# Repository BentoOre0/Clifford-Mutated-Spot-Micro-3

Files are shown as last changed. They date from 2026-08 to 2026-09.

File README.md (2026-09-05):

# Clifford: Mutated Spot Micro 3

<p align="center">
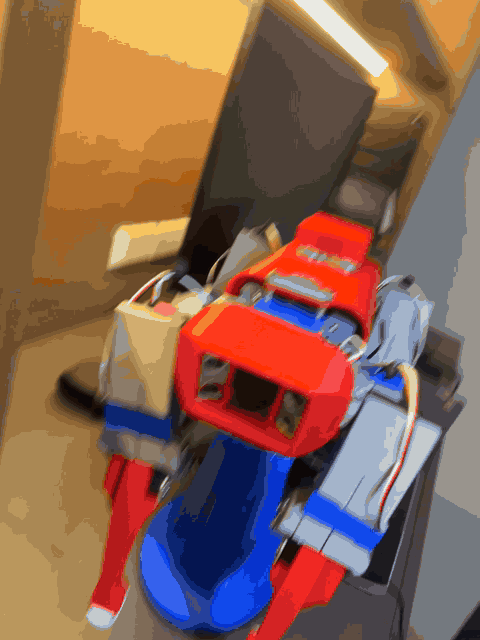
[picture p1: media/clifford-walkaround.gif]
Clifford, assembled, on the bench stand
  
</p>

**Clifford is a twelve-servo quadruped robot.** He started as
[Chris Locke's Nova SM3](https://novaspotmicro.com), an open-source Spot-Micro-class
design, and he exists in this form because the servos that design is drawn around were
not available to me. Substituting them broke every leg part at once, so the legs were
redesigned from scratch around a different servo.

That is the project: **not a build of someone else's kit, and not a design of my own from
nothing, but the engineering in between.** Adapting a working system to parts it was never
meant to use, and getting it running again.

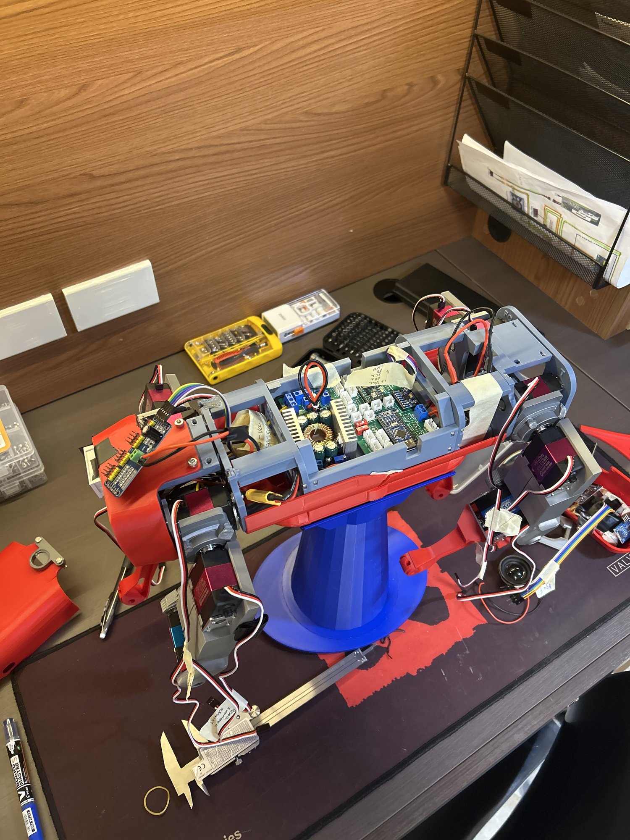
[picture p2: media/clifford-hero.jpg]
Clifford during electronics integration


*Mid-integration on the bench. The grey coax and femur and the red tibia are my geometry.
The calipers in the corner are not set dressing: every part here was redrawn against
measurements.*

---

## The problem that started everything

I built this in the Philippines, where a significant share of the original bill of
materials was not practically sourceable. The servos were the ones that mattered.

The Nova SM3 is drawn around the **DS3218** servo, which bolts down through **four sets of
mounting holes.**

The only servos I could actually buy were the **RDS3218**, which does not have those holes.
It hangs in a **U-shaped metal bracket** instead.

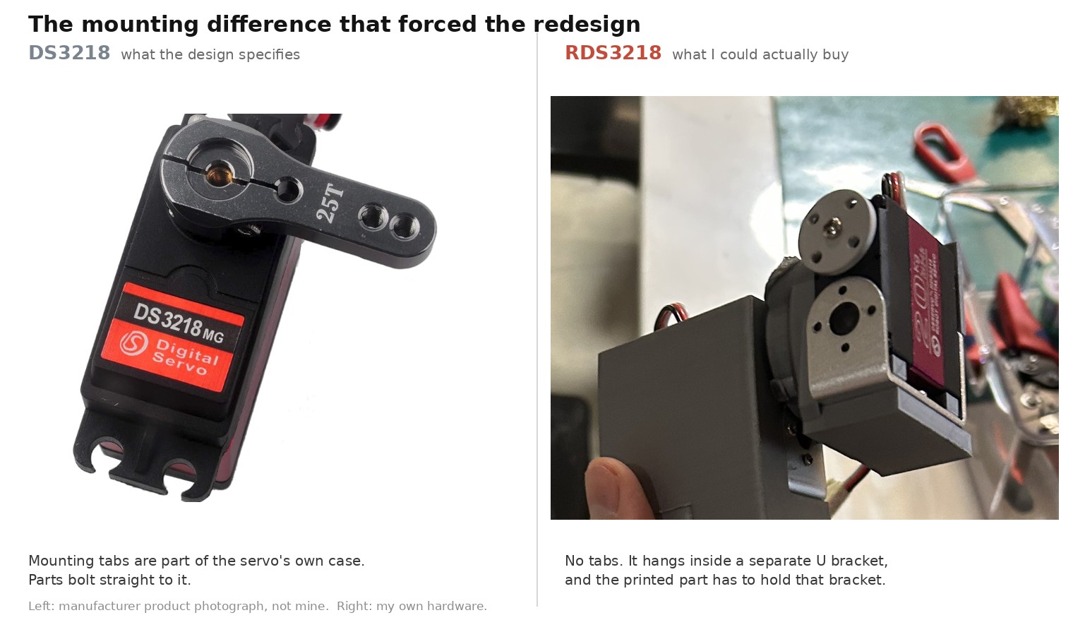
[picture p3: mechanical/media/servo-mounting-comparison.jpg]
DS3218 against RDS3218


PROBLEM: The mounting scheme every leg part was built around simply does not exist on the replacement
part. The pockets, the bosses and the screw features were all designed to grip something
that no longer had anything to grip.

SOLUTION: Each leg part had to be redesigned from scratch around a completely different way of
holding a servo, while keeping the servo horn geometry and axis position (To the best of my ability).

**Twelve servos, all 270 degrees:** 8x RDS3218 at 20 kg.cm for the coax and femur joints,
4x RDS3235 at 35 kg.cm for the knees.

---

## What I changed

| | Chris Locke's | Mine |
|---|---|---|
| Robot concept, gaits, servo motion engine, master/slave architecture | all of it | |
| Original leg geometry | the starting point | **redesigned from scratch around the RDS3218 bracket** |
| Coax, femur and tibia parts | original | **mine**, horn interface preserved |
| Printing and assembly | | **mine** |
| Wiring diagram | v5.2b pictogram | **revised for parts I could source, plus one fault corrected** |
| Power distribution | cascaded converters | **reworked to parallel** |
| PCB assembly, wiring and bring-up | | **mine** |
| Per-subsystem bench test sketches | | **mine** |
| Firmware v4.2 to v5.1 | his | |
| Firmware v6.0 restructure | behaviour is his | **reorganisation is mine** |
| Servo calibration values | **still his**, and that is the open problem | see [Status](#status) |

---

## The engineering journey

<table>
<tr>
<td width="33%" valign="top">
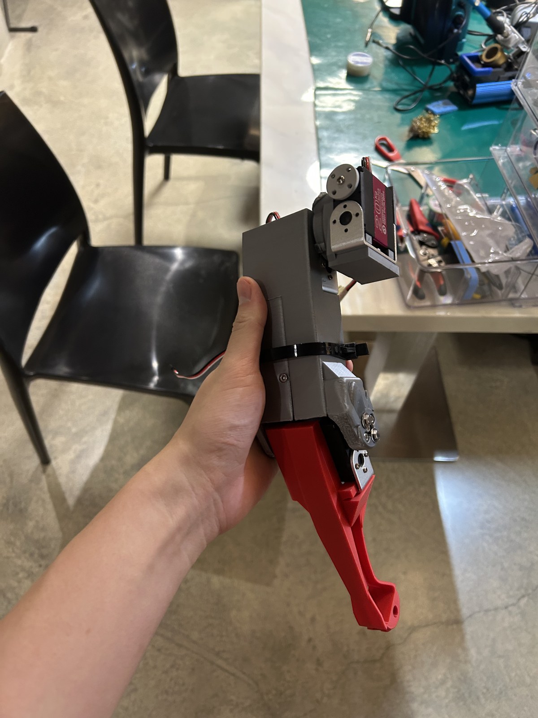
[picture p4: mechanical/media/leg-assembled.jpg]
Assembled leg

<br><b><a href="mechanical/README.md">Mechanical</a></b><br>
A servo that mounts in a bracket instead of through holes, and the three parts that had
to be redrawn because of it. Original against modified, measured from the meshes.
</td>
<td width="33%" valign="top">
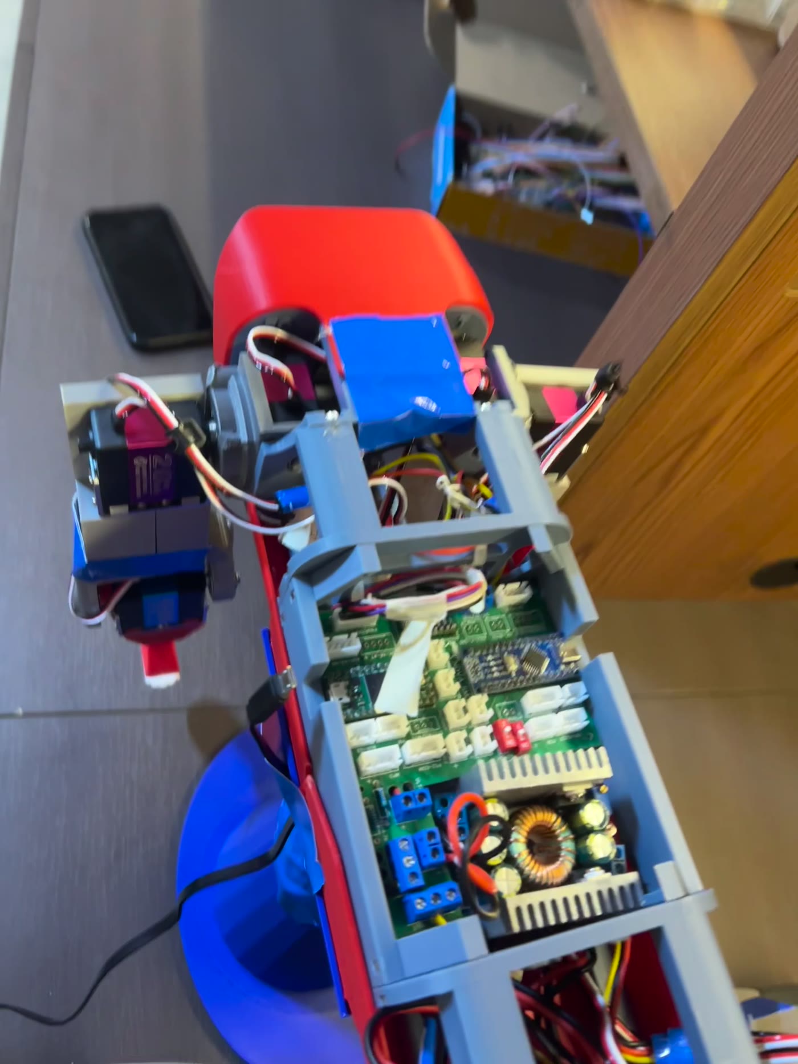
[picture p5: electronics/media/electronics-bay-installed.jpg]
Electronics bay

<br><b><a href="electronics/README.md">Electronics</a></b><br>
A reference design that had gone stale, traced by hand against real hardware. Power
rework, a wiring fault, and one subsystem brought up at a time.
</td>
<td width="33%" valign="top">
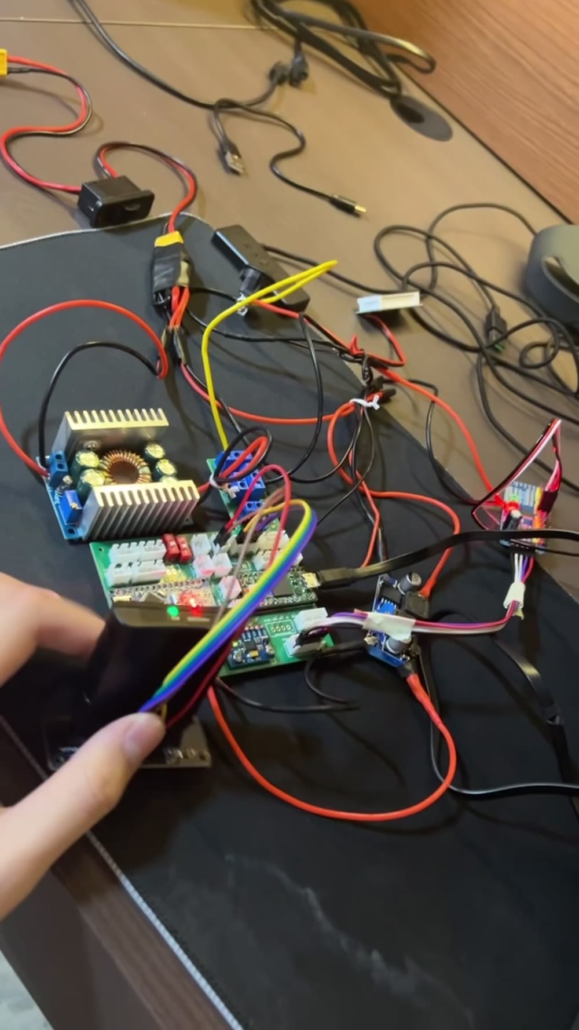
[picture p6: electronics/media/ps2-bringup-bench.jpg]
PS2 bring-up

<br><b><a href="firmware/README.md">Firmware</a></b><br>
6,390 lines in one file, 85 undocumented protocol strings, and an 812-line function.
Restructured into something maintainable, with two real bugs found on the way.
</td>
</tr>
</table>

> ### [Open the full corrected wiring diagram](electronics/wiring/wiring-diagram-modified.png)
>
> 6000 x 4712, every pin labelled, every revision marked on the sheet. The upstream
> pictogram had a short in it; this is the corrected drawing.

---

## Status

Being straight about where this actually is:

| | |
|---|---|
| Leg redesign, printing, assembly | Complete |
| Electronics integration | Complete |
| Wiring diagram corrected and revised | Complete |
| Per-subsystem bench tests | Passing |
| PS2 receiver verified against live serial output | Yes |
| Firmware v6.0 restructure | Complete, compiles clean for both boards |
| **Servo recalibration for my servos** | **Not done had to fly out to UBC** |
| **Walking** | **Not working yet** |

---

## Repository layout

```text
media/           hero photography and the walkaround clip
mechanical/      the leg redesign: CAD, comparisons, build photos
electronics/     wiring, power, PCB, bring-up
firmware/        the Arduino sketches and the v6.0 write-up
```

Chris Locke's original geometry lives in
[`mechanical/cad/original/`](mechanical/cad/original/) under his filenames and is never
edited in place. 

---

## Credit and licence

**Original project: Chris Locke** (`cguweb@gmail.com`).
[novaspotmicro.com](https://novaspotmicro.com) ·
[GitHub](https://github.com/cguweb-com/Arduino-Projects/tree/main/Nova-SM3) ·
[Thingiverse](https://www.thingiverse.com/thing:4767006) ·
[Instructables](https://www.instructables.com/Nova-Spot-Micro-a-Spot-Mini-Clone/).
MIT licensed, see [LICENSE](LICENSE), Copyright (c) 2021 Christopher M. Locke.

The robot, the pcB, its gaits, its servo motion engine and its master/slave architecture are his.
The wiring diagram here is a revision of his v5.2b pictogram: the base artwork is his and
the revisions are mine.

**Third-party images.** The DS3218 photograph in the
[mechanical write-up](mechanical/README.md) is a manufacturer product image from a retail
listing, reproduced for comparison only. It is not my photograph.

**Third-party parts.** **Ozzymat**'s [Youtube](https://www.youtube.com/@ozzymat61) was a reference for looking at physical assemblies of the original NOVA which is different. I used this as insiration for ideas on how I can make a physically new part.

**Leg redesign, electronics and v6.0 firmware restructure: Jeremy Aidan Yu.** The v6.0
restructure was done with Claude Code, which is stated here, in the firmware write-up and
in the source headers.

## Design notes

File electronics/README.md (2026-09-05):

# Electronics: wiring a reference design that had gone stale

← [back to the main README](../README.md)

---

## What is actually inside

Before any diagrams, this is the real thing:

Electronics installed

*Looking down into the open electronics bay of the assembled robot. The controller PCB is
at the bottom of the frame with the servo harnesses running out to the legs, and the
step-down converter sits above it. I hadn't soldered initensively before, I soldered everything here (PCB, MCUs, XT60 connectors) and tested connections.*

<table>
<tr>
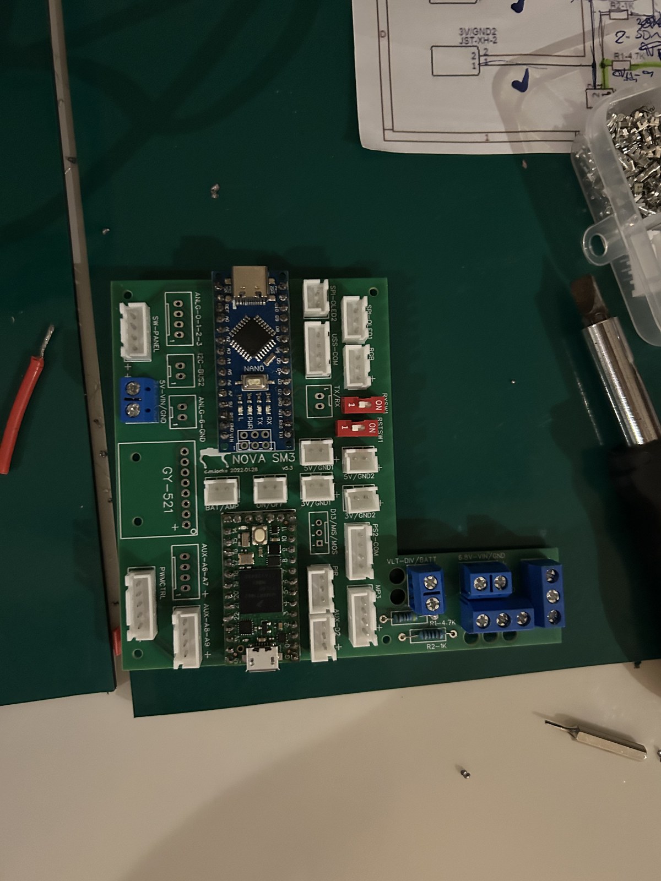
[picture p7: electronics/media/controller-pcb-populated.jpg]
Controller PCB populated
<td width="50%"></td>
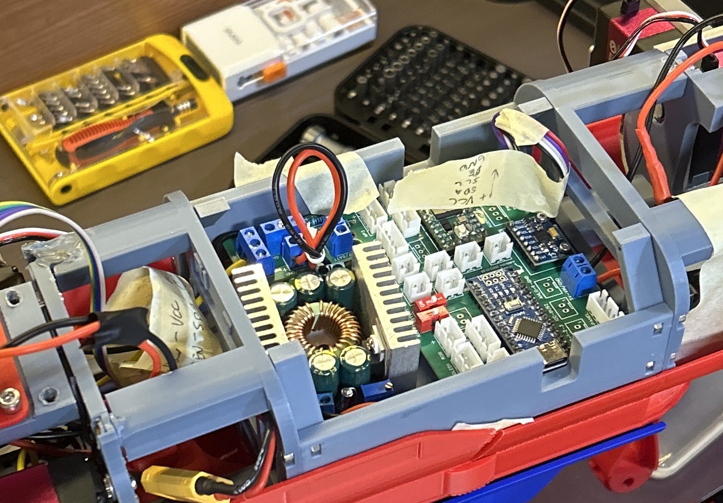
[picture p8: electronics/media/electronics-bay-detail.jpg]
Electronics bay detail
<td width="50%"></td>
</tr>
<tr>
<td colspan="2"><em>Left: the Nova SM3 controller board after I populated and soldered it,
before installation. It is the Chris' project's own PCB (which I had to adopt by rerouting components), not an off-the-shelf module: JST servo
headers, an Arduino Nano, an MPU6050 breakout, a DIP switch and screw terminals. Right: the
same board fitted in the chassis beside the converter. The masking-tape labels reading
<code>+VCC / SDA / SCL / OE / GND</code> are mine, written during bring-up so the I2C and
output-enable lines could be traced against the drawing without counting pins every
time.</em></td>
</tr>
</table>

**What has to be powered:** twelve servos, two microcontrollers, an IMU, three PIR sensors,
two ultrasonic sensors, an OLED, four addressable RGB LEDs, an MP3 player and a speaker,
all from one LiPo pack. 

---

## The pictogram was wrong. The schematic is what proved it

The upstream project ships two wiring documents, a **schematic** and a **pictogram**, and
they do not agree with each other. The schematic is accurate. The pictogram belongs to an
older, deprecated revision, and following it as drawn does not give you a working robot.

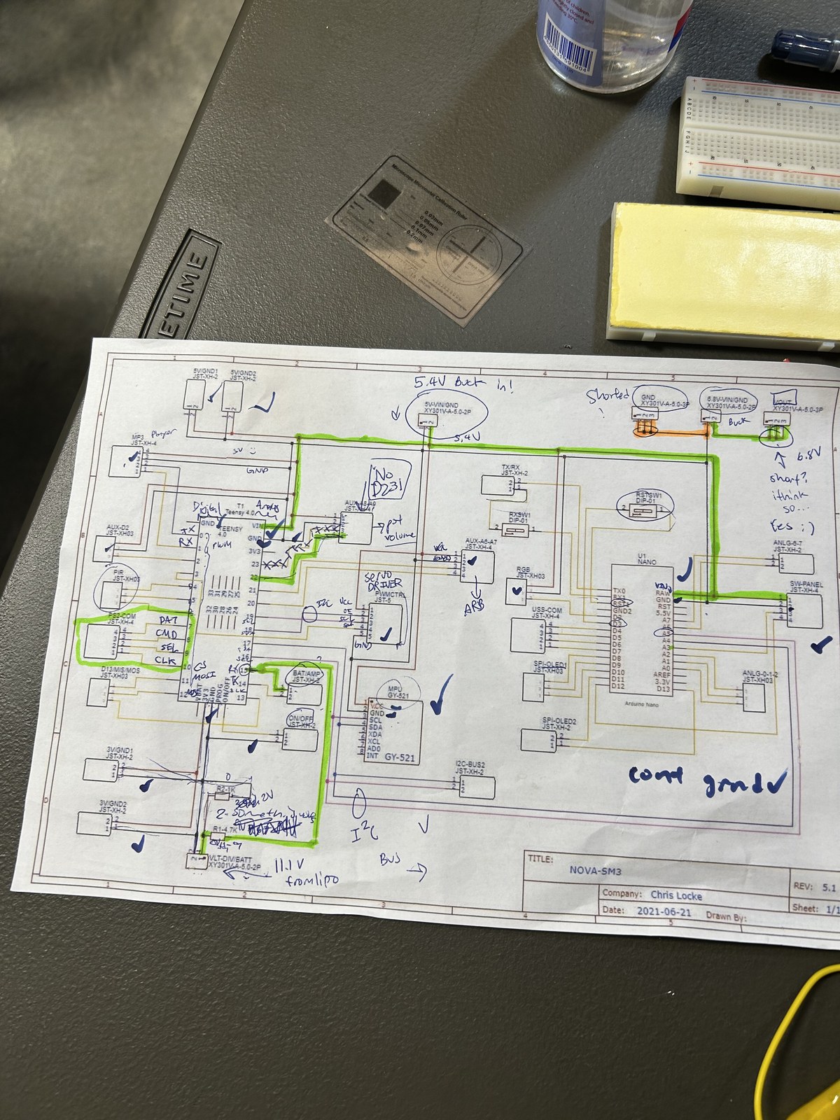
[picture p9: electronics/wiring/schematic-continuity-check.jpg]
Schematic used as a test sheet


*Chris Locke's REV 5.1 schematic, printed and used as a live test sheet. This is the
drawing that held up under testing, which is why it became my reference. Blue ticks are
nets I confirmed with a multimeter, green highlighter follows the ones I was chasing to get an understanding of the structure, the
PS2-COM header is hand-labelled DAT / CMD / SEL / CLK because that mapping had to be worked
out, and `cont gnd` with a tick at the bottom records ground continuity confirmed. I did this by doing a disjoint set union approach for continuity.
The ports for grounds werenodes, the traces between them are edges, just run DSU and make sure everything is continuous!*

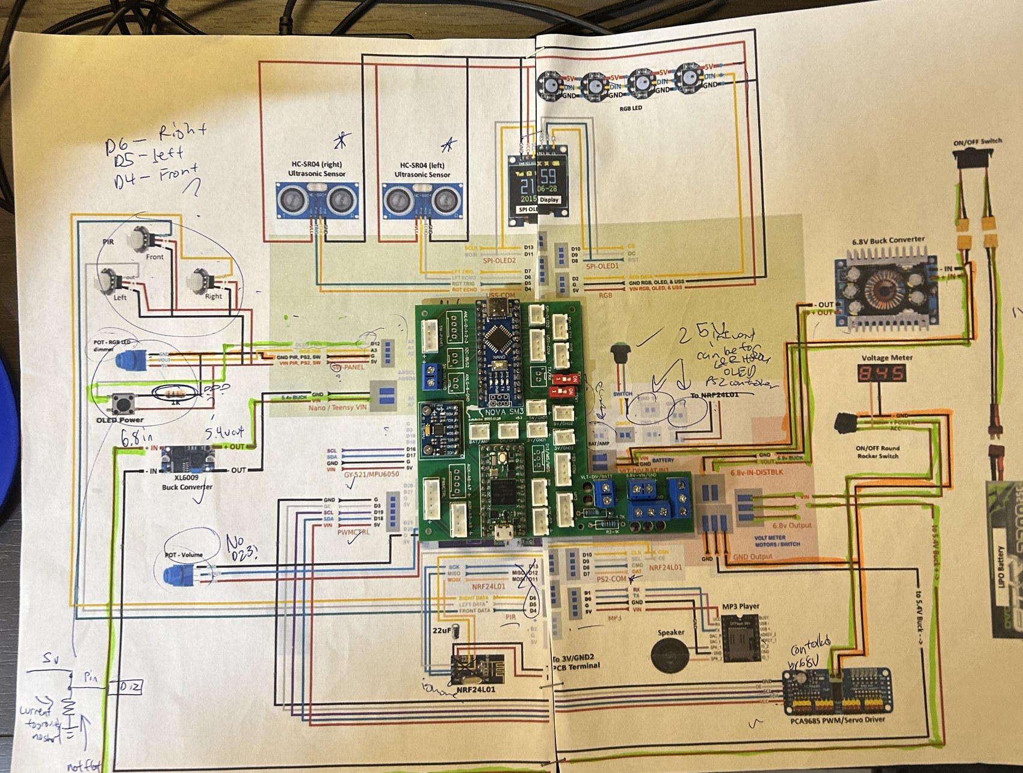
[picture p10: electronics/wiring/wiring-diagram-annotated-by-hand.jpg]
Pictogram traced by hand


*The v5.2b pictogram, traced in highlighter along the power path with pen notes throughout*

I found quite a few errors, some by tracing and some by physical building and realising things didnt turn on consistently.
The output of all of this is a **corrected pictogram**, which carries its own
revision block that also shows my modifications:

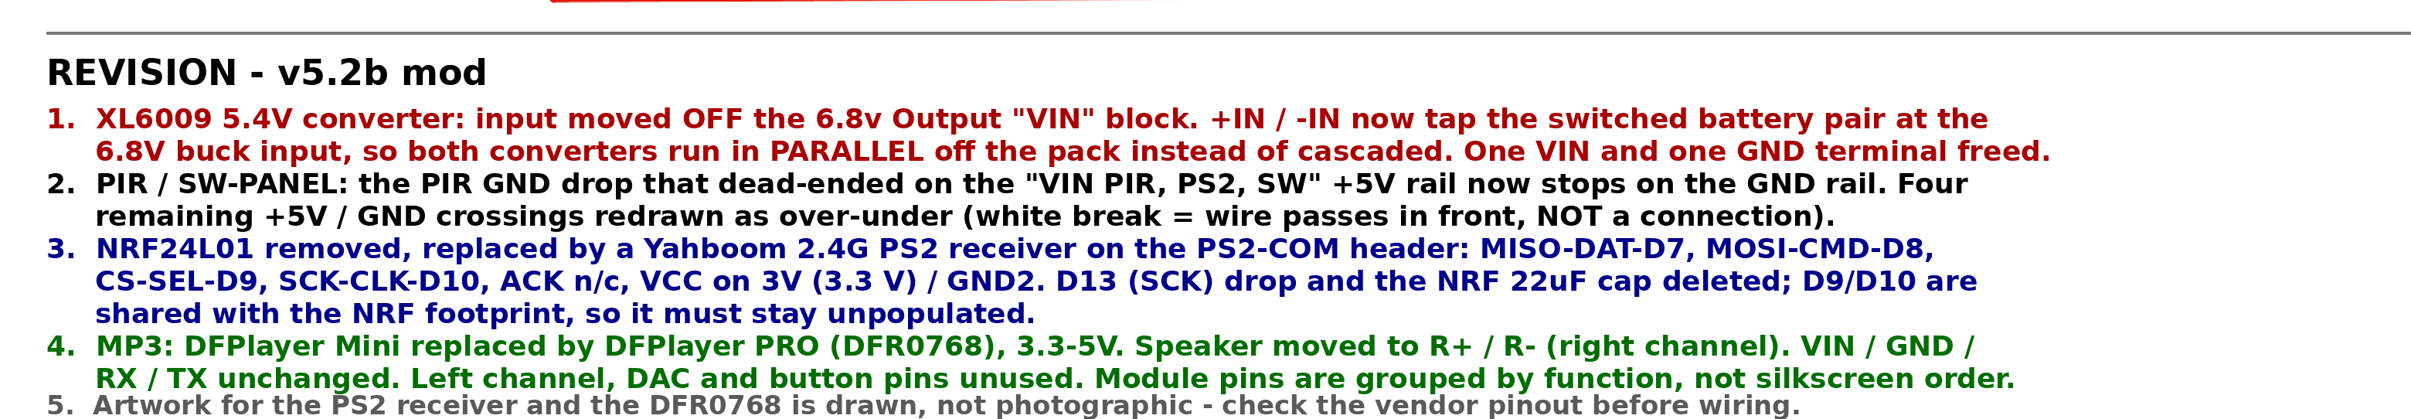
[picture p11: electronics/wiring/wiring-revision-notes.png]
Revision block


> ## [Open the full corrected wiring diagram](wiring/wiring-diagram-modified.png)
>
> `electronics/wiring/wiring-diagram-modified.png`, 6000 x 4712. Every pin is labelled and
> every revision is marked on the sheet. This is the drawing to build from.

The base artwork is Chris Locke's. The revisions and the revision block are mine. It is
committed as the drawing itself rather than redrawn or summarised, so the documentation and
the artifact cannot drift apart the way the upstream pair did.

---

## Revision 1: cascaded converters reworked to parallel

**The symptom.** Startup was inconsistent. When I connected the ps2 controller and the servo driver to the pcb
while powering it, it would inconsistently start up. MCUs would not even power sometimes.
However if I didn't plug them in or plugged them in hot, these components would turn on.

**The hypothesis.** - one thing that I could see for sure is that there was a consistent **inconsistent** start up problem. When I put the 
ps2 controller and servo driver it would have a hard time starting up despite drawing only very little amps (don't remember the number).
I thought there could be some **impedance** problem between the bucks and all components: testing with multi meter I saw the 6.8V buck converter sagged 
causing the voltage down stream to sag as well. 

**What the reference design did.** The XL6009 5.4 V converter took its input from the
**6.8 V converter's output block**. The two converters therefore ran **in series**.

**The fix.** I moved the XL6009 input **off** the 6.8 V output block and onto the switched
battery pair at the 6.8 V buck input. **Both converters now run in parallel off the pack**,
so neither sees the other's output impedance.

> Revision 1, in the drawing's own words: *"XL6009 5.4V converter: input moved OFF the 6.8v
> Output 'VIN' block. +IN / -IN now tap the switched battery pair at the 6.8V buck input, so
> both converters run in PARALLEL off the pack instead of cascaded. One VIN and one GND
> terminal freed."*

## Revision 2: the PIR short

This is the fault that made the exercise worth doing. On the pictogram, **the PIR ground
drop terminated on the `VIN PIR, PS2, SW` +5 V rail** instead of the ground rail.

Wired as drawn, that ties a ground return straight to a +5 V rail, which is a short across
the sensor supply.

So I fixed it. I mentioned the changes I wanted to claude and it ran the photoshop for me.

## Revisions 3 to 5: component substitutions

| Original | What I fitted | Consequence |
|---|---|---|
| NRF24L01 plus a custom-built remote | **Yahboom 2.4 G PS2 receiver** | On the PS2-COM header: MISO-DAT-D7, MOSI-CMD-D8, CS-SEL-D9, SCK-CLK-D10, ACK n/c, **VCC on 3.3 V**, GND2. The D13 (SCK) drop and the NRF 22 uF cap are deleted. D9/D10 are shared with the NRF footprint, **so that footprint must stay unpopulated.** |
| DFPlayer Mini | **DFPlayer PRO (DFR0768)**, 3.3 to 5 V | Speaker moved to R+ / R- (right channel). VIN / GND / RX / TX unchanged; left channel, DAC and button pins unused. |

The receiver itself had nowhere to live, since the body was designed around a radio
soldered to the board. It ended up in a backpack borrowed from the Nova SM2, mounted on a
new back panel so it protrudes from the body like a tail and keeps its antenna outside the
electronics bay. That is documented on the
[mechanical page](../mechanical/README.md#the-tail-borrowing-a-backpack-from-the-nova-sm2).

Revision 5 is a caveat I put on the drawing rather than a change: the artwork for the PS2
receiver and the DFR0768 is **drawn, not photographic**, so check the vendor pinout before
wiring.

The PS2 substitution is also why the firmware runs on the older PS2 code path rather than
upstream's newer nRF path. See the [firmware write-up](../firmware/README.md).

---

## Bring-up: one subsystem at a time

The decision that mattered most was **not** to assemble everything, flash the full
firmware, and start guessing.

The inherited firmware is large, it drives a lot of peripherals, and a fault could be in my
soldering, my wiring, my power rail, or somebody else's code. Debugging all of those at once
is how you lose a week. Given that the reference documentation had already proven unreliable,
assuming any of it was correct would have been a mistake.

So I wrote [`firmware/Tests/`](../firmware/Tests/): eight standalone sketches, one per
peripheral, each of which deliberately includes **none** of the main firmware. A pass proves
wiring and hardware, not the main sketch.

| Sketch | Board | Under test | Pins, as defined in the sketch |
|---|---|---|---|
| `Test_PWM_Servos` | Teensy 4.0 | PCA9685 and 12 servos | `OE_PIN 3`, jogged over PS2 |
| `Test_PS2` | Teensy 4.0 | PS2 receiver | DAT 7, CMD 8, SEL 9, CLK 10 |
| `Test_MPU6050` | Teensy 4.0 | IMU | SDA2 17, SCL2 16 |
| `Test_PIR` | Teensy 4.0 | 3x PIR | front 4, left 5, right 6 |
| `Test_MP3` | Teensy 4.0 | DFPlayer | volume pot 20 |
| `Test_Ultrasonic` | Arduino Nano | 2x HC-SR04 | L trig 7 / echo 6, R trig 5 / echo 4 |
| `Test_OLED` | Arduino Nano | SSD1331 96x64 | active pin 12 |
| `Test_NeoPixel` | Arduino Nano | 4x WS2812 | data 2, brightness pot A3 |

Each carries an explicit pass criterion, so "it did something" does not get mistaken for
"it works".

<table>
<tr>
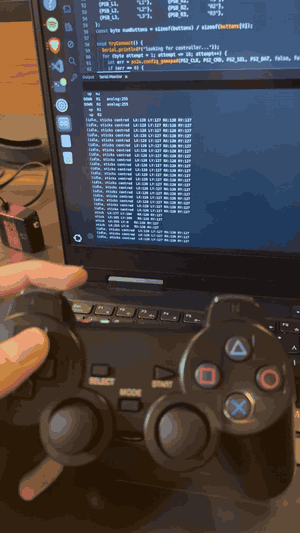
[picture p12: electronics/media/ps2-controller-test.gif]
PS2 controller tested against live serial output
<td width="42%"></td>
<td width="58%">PS2 bring-up bench rig</td>
</tr>
<tr>
<td colspan="2"><em>Left: the PS2 receiver being verified. Every button press and stick
movement is echoed by the serial monitor on the laptop, which is the firmware's
<code>ps2_debug_report()</code> running. That is what "the receiver works" actually looks
like: not a robot twitching, but a named input arriving as a value you can read. Right: the
rig it was done on, converter and controller board and jumper harness on the bench, well
away from twelve servos.</em></td>
</tr>
</table>

---

## Hazards worth knowing

These are in the source as warnings because they were live problems, not hypotheticals.

**The Teensy 4.0 is not 5 V tolerant.** From
[`Test_PS2.ino`](../firmware/Tests/Test_PS2/Test_PS2.ino): *"The PS2 receiver is a 3.3V
part. The Teensy 4.0 is ALSO 3.3V and is NOT 5V tolerant, do not feed the receiver 5V and
then wire DAT back to the Teensy."* The failure mode is nasty because the receiver **works**
on 5 V. It just quietly destroys the microcontroller through the data line. The corrected
drawing accordingly puts the receiver's VCC on 3.3 V.

**`OE_PIN` is active LOW, and boot order matters.** Driving OE low *enables* the servos. It
is held high through boot until the PS2 link is up, because the PWM driver interferes with
the receiver; without that sequencing the robot lurches on power-up. Servo output arms about
a second after boot.

**Current sense and battery sense share one pin.** `AMP_PIN` and `BATT_MONITOR` are both
**A1**. The robot physically cannot measure servo current and battery voltage at the same
time. This is inherited from the original design and is an architectural limitation, not a
bug.

**Debug flags block an untethered boot.** On a Teensy, printing to a serial port with
nothing attached stalls the board, so any debug flag left set in `NovaConfig.h` makes the
robot appear completely dead the moment you unplug the laptop.

---

## What is not documented here

- **No measurements recorded.** No current draw figures, no rail voltages under load, no
  scope captures. The reasoning above and the corrected drawing are the evidence; I did not
  log the readings that led me there and I am not going to invent them after the fact.
- **No continuity log.** The tracing happened, and the annotated printouts above are what
  survives of it. The individual readings were not written down.
- **No bill of materials** for the substituted parts beyond what the drawing names.

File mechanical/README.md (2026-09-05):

# Mechanical: redesigning the legs around a servo that mounts differently

← [back to the main README](../README.md)

---

## The constraint

The Nova SM3 is drawn around the **DS3218** servo. That servo bolts down through **four
sets of mounting holes**, and every leg part in the original design is built to take it:
pockets sized to the case, bosses positioned under those four hole sets, walls that clamp
around the body.

The only servo I could buy was the **RDS3218**. Electrically and dimensionally it is a
close relative. Mechanically it is not: it has no four-hole pattern. It **hangs in a
U-shaped metal bracket**, and the bracket is how it attaches to anything.

DS3218 against RDS3218

*The whole mechanical project in one image. On the DS3218 the mounting tabs are moulded into the case,
so a printed part bolts directly to the servo. The RDS3218 has none, and is instead
suspended in a separate metal bracket, which means the printed part has to capture the
bracket rather than the servo. The DS3218 photograph is a manufacturer product image
reproduced for comparison and is not my own.*

**The servos, all 270 degrees:**

| Joint | Servo | Torque | Count |
|---|---|---|---|
| Coax (hip) | RDS3218 | 20 kg.cm | 4 |
| Femur (thigh) | RDS3218 | 20 kg.cm | 4 |
| Tibia (knee) | RDS3235 | 35 kg.cm | 4 |

---

## The one thing that could not move

> **Preserve the servo horn interface exactly. Rebuild everything around it.**

The horn is where the joint axis lives. Shift it a few millimetres and every link length
in the leg changes, and the hand-tuned gait multipliers in
[`Gaits.ino`](../firmware/Nova-SM3_teensy-v6.0/Gaits.ino) stop describing the robot. (Goal is to minimise this)

---

## How the bracket problem was actually solved

The RDS3218 sits inside its U bracket, which leaves two things to design against:

**1. Two protrusions that slot between the bracket arms.** Rather than trying to clamp the
servo body, the printed part carries two protrusions that locate into the gap between the
U bracket and the servo, so the bracket itself does the holding and the print just captures
it.

**2. Four holes underneath.** The bracket is then fixed down through four holes in the
bottom face of the part.

**3. A clearance cut for the far end.** The RDS3218 has a protrusion on the end opposite
the horn, the mating feature for the other side of the U bracket. That protrusion turned
out to be **axially aligned with the servo horn and with the bearing boss**, which meant a
single extrude cut along that axis cleared it. 

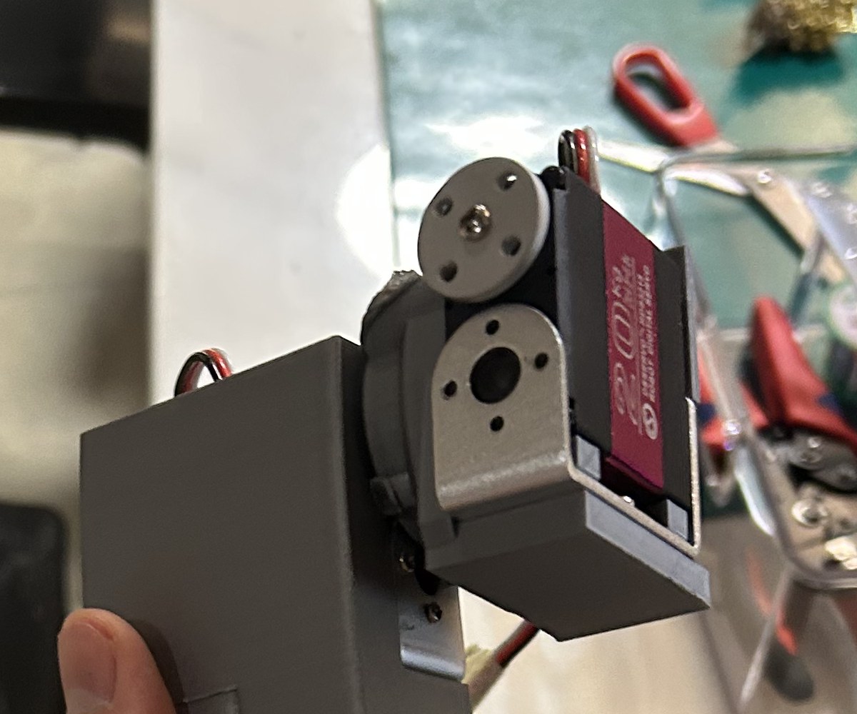
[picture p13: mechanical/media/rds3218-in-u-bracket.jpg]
RDS3218 sitting in its U bracket


*The arrangement the parts had to be redesigned for. The servo is held by the aluminium U
bracket wrapped around it, not by screws through its own case, and the printed part is
built to capture that bracket. The horn, with its five-hole pattern, is the one feature
carried over unchanged from the original design. The magenta label reads 20 kg.*

<table>
<tr>
<td width="50%">Assembled leg, front</td>
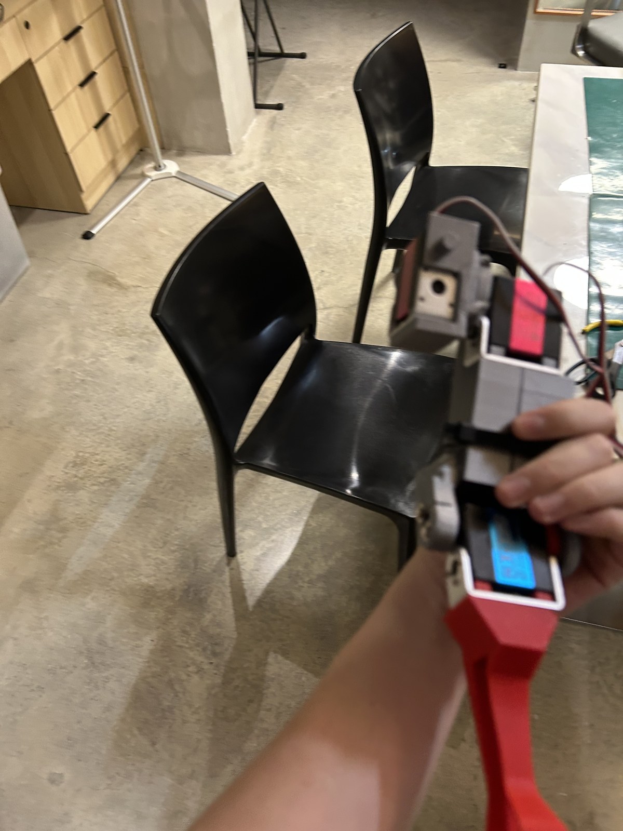
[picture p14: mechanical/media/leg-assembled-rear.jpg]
Assembled leg, rear
<td width="50%"></td>
</tr>
<tr>
<td colspan="2"><em>A complete leg. Grey parts are the coax and the two femur pieces, the
red part is the tibia. The parting line across the grey femur with the tie around it is
the joint between femur body 1 and body 2: like the original, the femur prints as two
pieces. The servos are visible sitting in their brackets.</em></td>
</tr>
</table>

---

## How the parts were modified

The parts are not redrawn from scratch in CAD, and not mesh-edited either. The workflow
was chosen to **preserve geometry that still worked**, in particular the TPU foot mounting and the servo horn mounting
holes and shape of legs, which were among the few original components I could still use:

1. **Tinkercad** for the rough cutting and the crude changes, working directly on the
   original STL. Fast, and good enough to hack away what the new servo made irrelevant
   while leaving the features worth keeping alone.
2. **Formware** to patch the mesh afterwards. Boolean cuts on an STL leave a damaged,
   non-manifold shell, and that has to be repaired before anything downstream will accept
   it. The intermediate file in my working set is still named after this step.
3. **SolidWorks** for the formal parametric work: import the repaired mesh as a base solid
   body, then add real sketches, boss-extrudes and cut-extrudes on top.

That sequence is visible in the feature trees. The coax part opens with `Imported1`,
Chris Locke's geometry, and then carries my own sketches and features on top of it:

<table>
<tr>
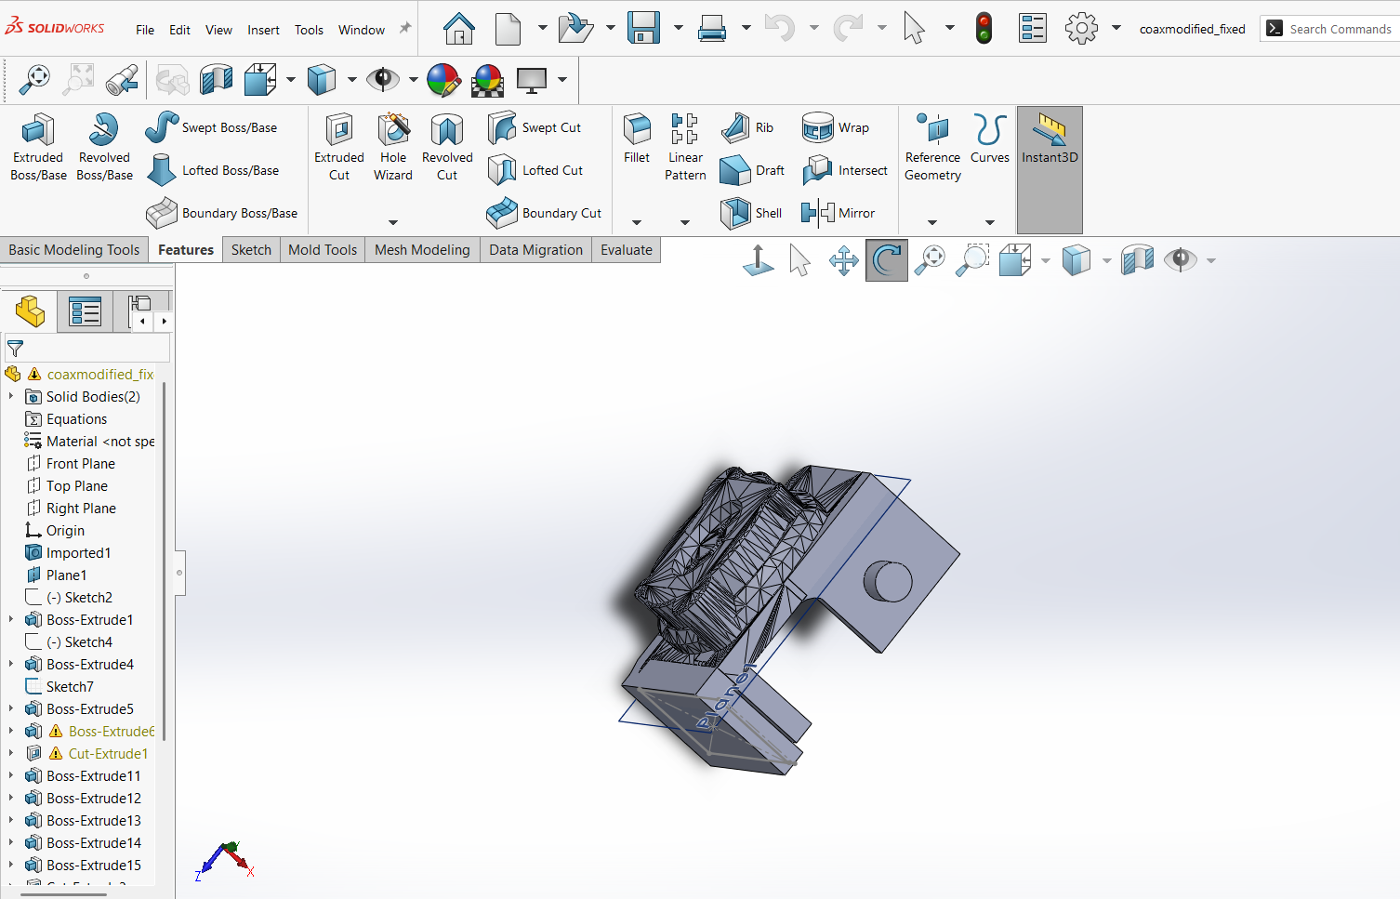
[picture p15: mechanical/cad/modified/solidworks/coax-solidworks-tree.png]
Coax feature tree
<td width="50%"></td>
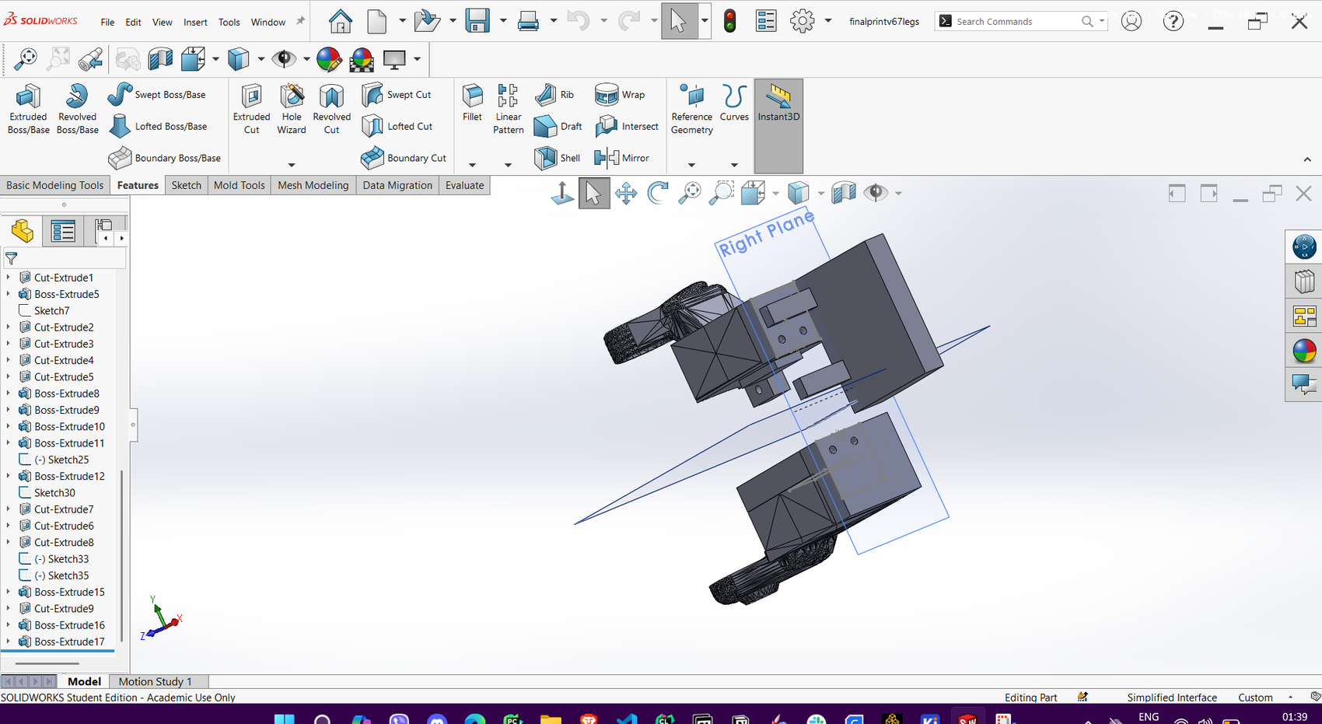
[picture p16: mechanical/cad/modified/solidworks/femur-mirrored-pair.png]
Femur mirrored pair
<td width="50%"></td>
</tr>
<tr>
<td colspan="2"><em>Left, the coax part (<code>coaxmodified_fixed</code>): the tree starts
at <code>Imported1</code> and then runs through Sketch2/4/7, Boss-Extrude1/4/5/11-15 and
Cut-Extrude1, all mine. Right, the femur document
(<code>finalprintv67legs</code>) showing the mirrored pair, with roughly twenty-five sketch
and feature operations behind it.</em></td>
</tr>
</table>

---

## Part by part

All dimensions and volumes below are **measured from the mesh geometry** of the files in
[`cad/`](cad/), not estimated or recalled.

### Coax (hip bracket)

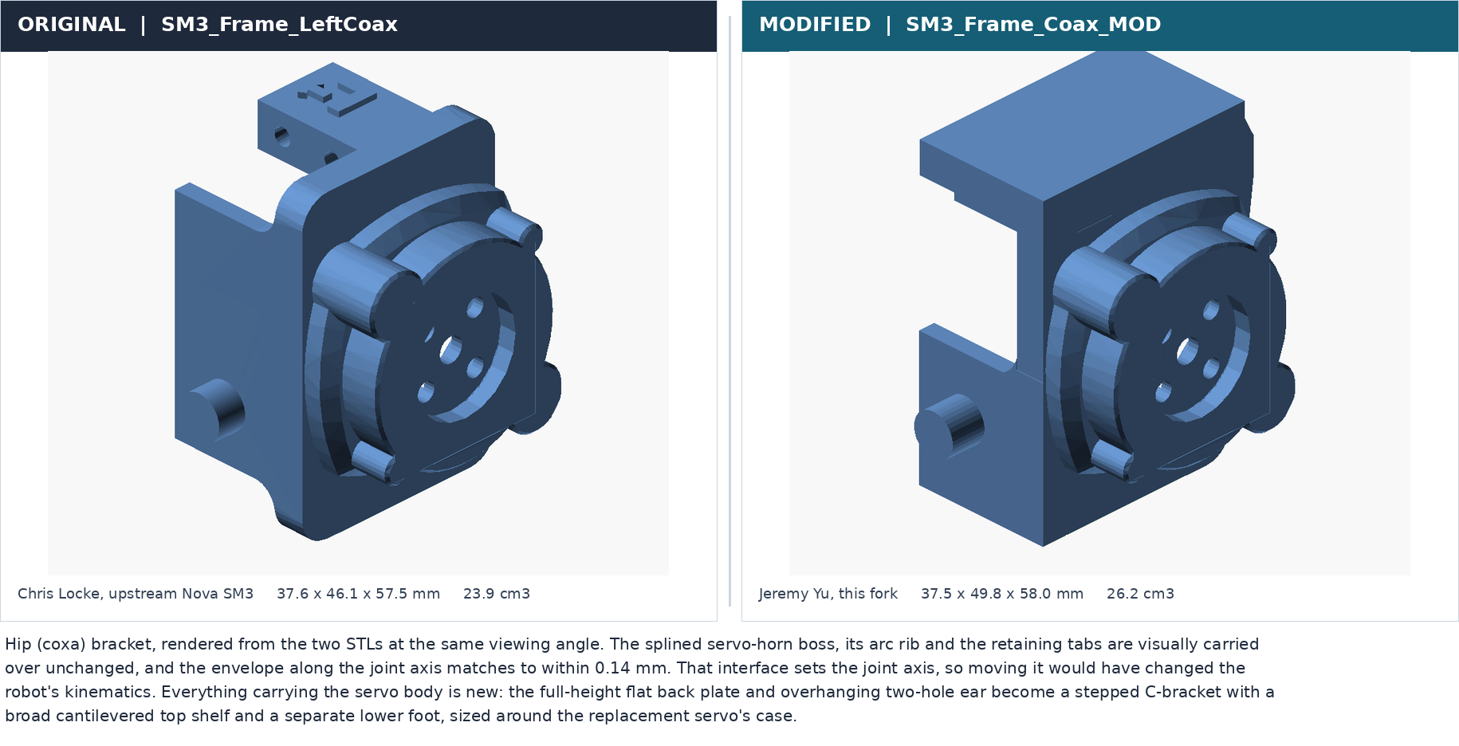
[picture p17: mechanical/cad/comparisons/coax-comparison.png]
Coax comparison


| | Original `SM3_Frame_LeftCoax` | Mine `modified_coax` | Change |
|---|---|---|---|
| Envelope | 37.59 x 46.13 x 57.50 mm | 37.45 x 49.77 x 57.97 mm | +3.64 mm across |
| Volume | 23.88 cm3 | 26.21 cm3 | +9.8% |

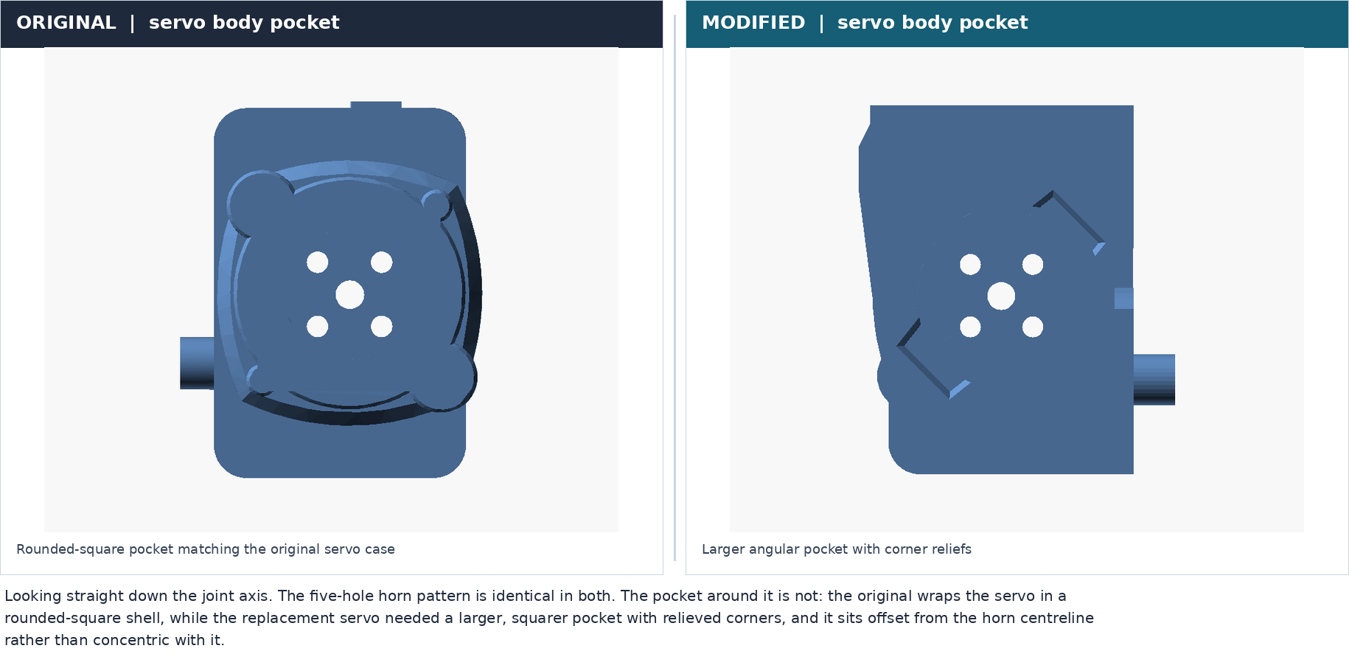
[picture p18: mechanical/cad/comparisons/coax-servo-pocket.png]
Coax servo pocket


Looking straight down the joint axis makes the point in one image: **same five-hole horn
pattern, completely different pocket.**

### Femur (two printed parts, before and after)

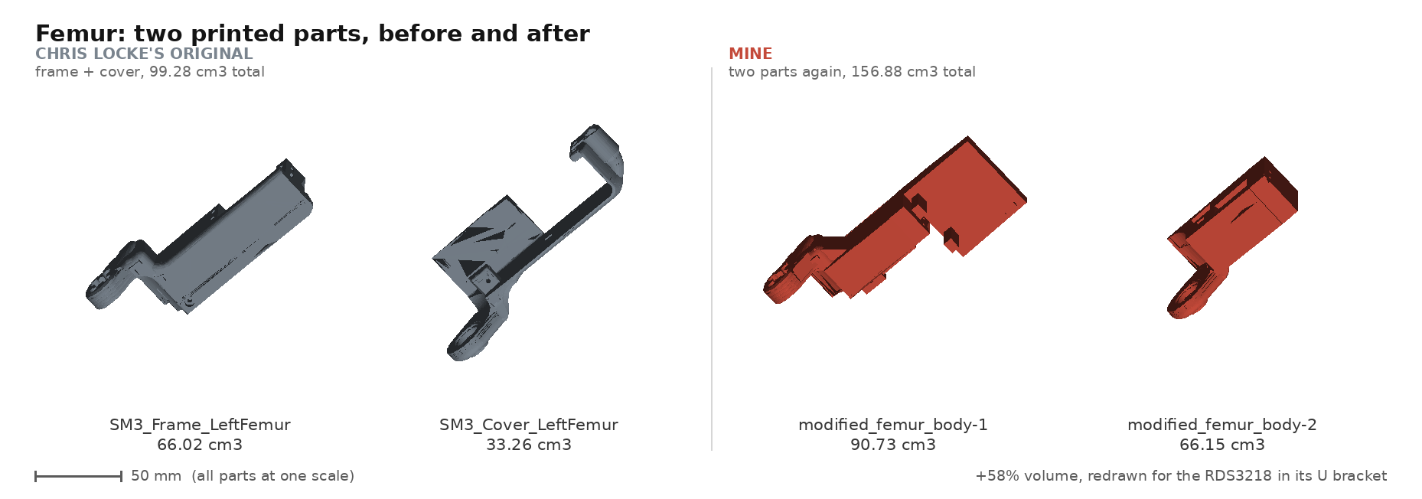
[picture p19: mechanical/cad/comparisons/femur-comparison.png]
Femur comparison


The original femur is **two printed parts that bolt together**, a structural frame and a
cover. Mine removes the cover and uses the same bolting mate while using the 2 protrusions
to hold the bracket and holes from the coax to hold the servo.

| | Original | Mine |
|---|---|---|
| Part 1 | `SM3_Frame_LeftFemur`, 66.02 cm3 | `modified_femur_body-1`, 90.73 cm3 |
| Part 2 | `SM3_Cover_LeftFemur`, 33.26 cm3 | `modified_femur_body-2`, 66.15 cm3 |
| **Assembly total** | **99.28 cm3** | **156.88 cm3** |

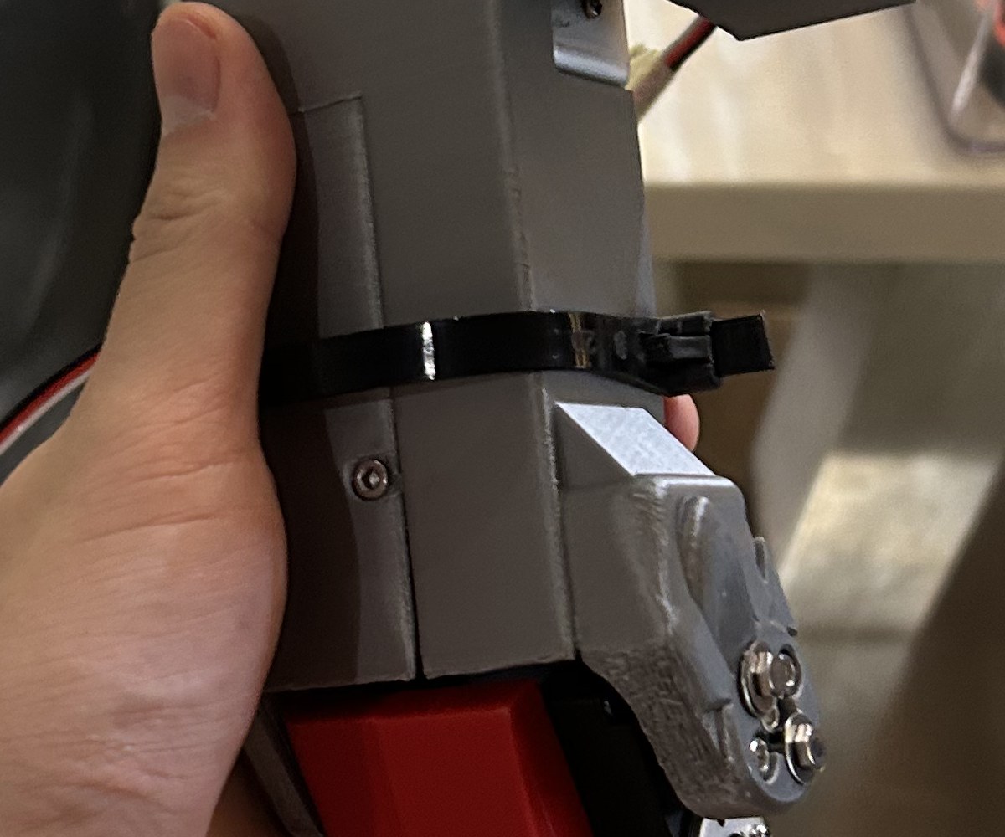
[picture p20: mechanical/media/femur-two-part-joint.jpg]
The joint between the two femur parts


### Why both femur halves live in one file

The two bodies are modelled together in a **single SolidWorks part document**, not as an
assembly of two parts, and that was a deliberate.

The obvious approach is an assembly: two part files, mated together. That does not work
well here. These bodies start life as **imported STL geometry**, which arrives with no
sketches, and nothing fully defined, so there is nothing dependable to mate
against. Aligning them that way was, in practice, very tricky and not trustworthy.

Modelling both halves in one document solves it. Each half can be **built off the other**
directly, because they share one origin and both are visible at once while working.

They are then spaced far enough apart in that same document to be printable exactly
as they sit, which is why the file doubles as the print plate.

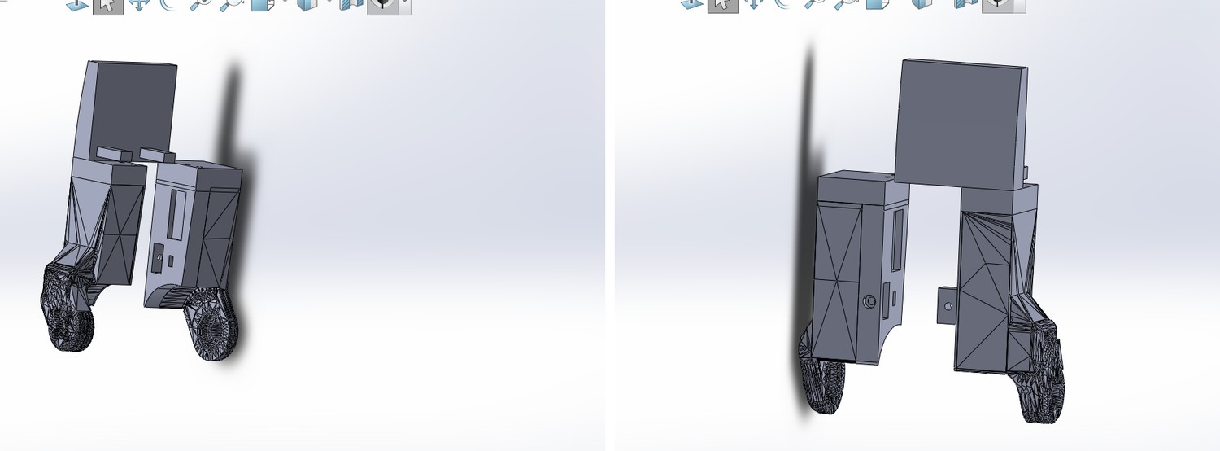
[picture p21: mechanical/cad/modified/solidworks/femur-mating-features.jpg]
Femur mating features


*Both femur halves in the one document (`finalprintv67legs`, `Solid Bodies(3)`), spaced for
printing and modelled against each other. The block protrusions on the facing surfaces are
the mating features.*

**How the halves join:** a **block protrusion** locates the two parts against each other,
and a screw pulls them together onto a **nut**, sitting in a pocket
that closes over as the part is built. 

[`modified_femur_plate.stl`](cad/modified/modified_femur_plate.stl) is that document
exported, and it is the file that was actually printed. `modified_femur_body-1.stl` and
`modified_femur_body-2.stl` are the same two bodies separated out so each can be inspected
on its own. The geometry is untouched; only the file container differs.

### Tibia (one printed part)

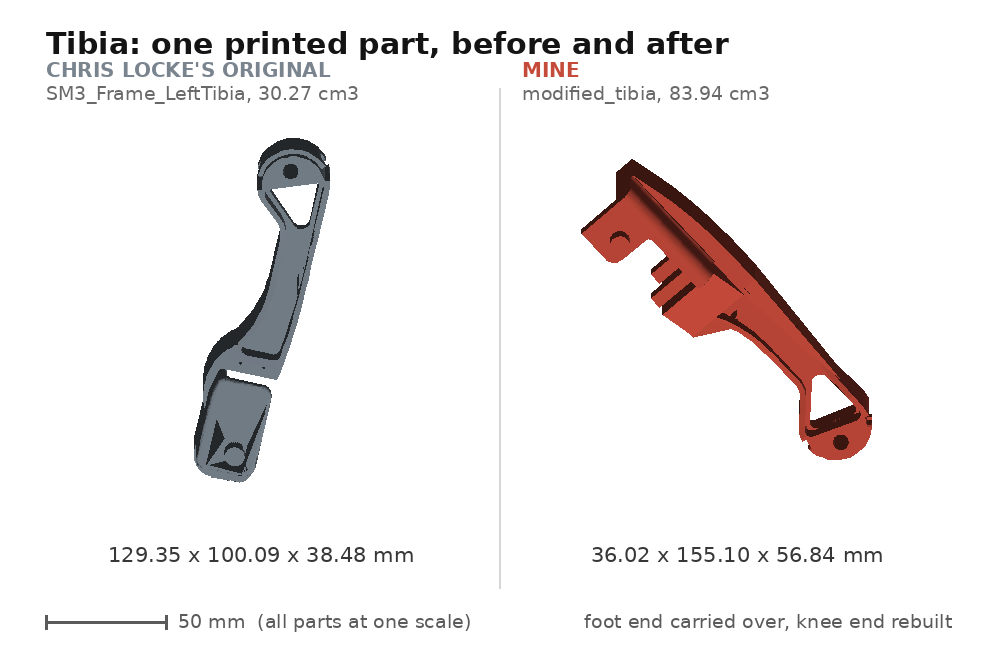
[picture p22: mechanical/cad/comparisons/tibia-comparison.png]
Tibia comparison


| | Original `SM3_Frame_LeftTibia` | Mine `modified_tibia` |
|---|---|---|
| Envelope | 129.35 x 100.09 x 38.48 mm | 36.02 x 155.10 x 56.84 mm |
| Volume | 30.27 cm3 | 83.94 cm3 |
| Triangles | 4,332 | 3,032 |

The tibia is a **single printed part** in both designs. The original is a slim curved arm
with a knee bore at one end and a light bracket at the other. Mine keeps the curved lower
arm and **the whole foot end with its TPU foot mounting**,
and replaces the light knee bracket with a full enclosure for the 35 kg.cm RDS3235.

I used the same mating mounts with the two protrusions and the extrude cut by the bearing boss.

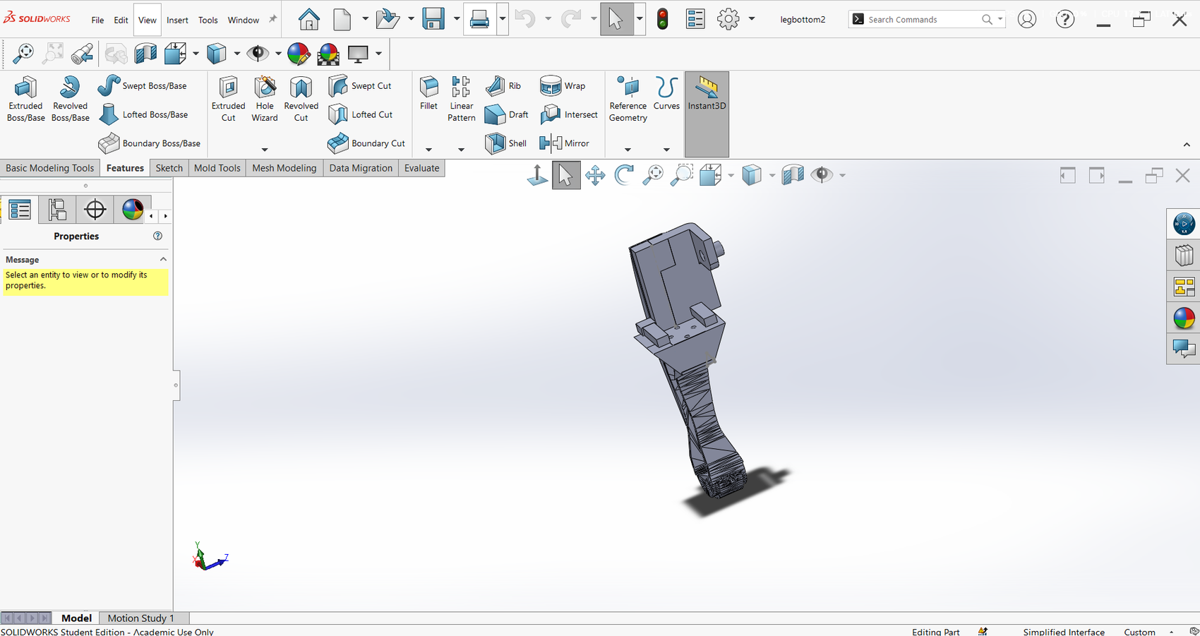
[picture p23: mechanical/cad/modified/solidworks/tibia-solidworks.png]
Tibia in SolidWorks


*The tibia in SolidWorks (`legbottom2`).*

---

## The tail: borrowing a backpack from the Nova SM2

Swapping the nRF24L01 for a PS2 receiver
([why](../firmware/README.md#why-ps2-and-not-the-nrf24l01)) left a part with nowhere to
live. The receiver is a bare module on a flying lead, and the SM3 body has no provision for
it, because the design it came from expects a radio soldered to the board.

The rear panel had to be reworked anyway. **I fitted a voltmeter**, the red seven-segment
display visible on the assembled robot, and the original panel was not big enough to take
it. So the panel was **enlarged** to carry the meter, and while it was being redrawn it
also became the mounting point for the receiver.

Rather than draw an enclosure for the PS2 remote from nothing, I took the **backpack from the SM2 version**, the
earlier robot in the same lineage, and put it on that panel. It houses the receiver and
**sticks out of the back like a tail**, which keeps the antenna outside the printed body
and out of the electronics bay from interference.

The panel uses the same fastening approach as the femur: **hidden nuts and screws**, with
the nuts captured inside the print rather than exposed on the outside face.

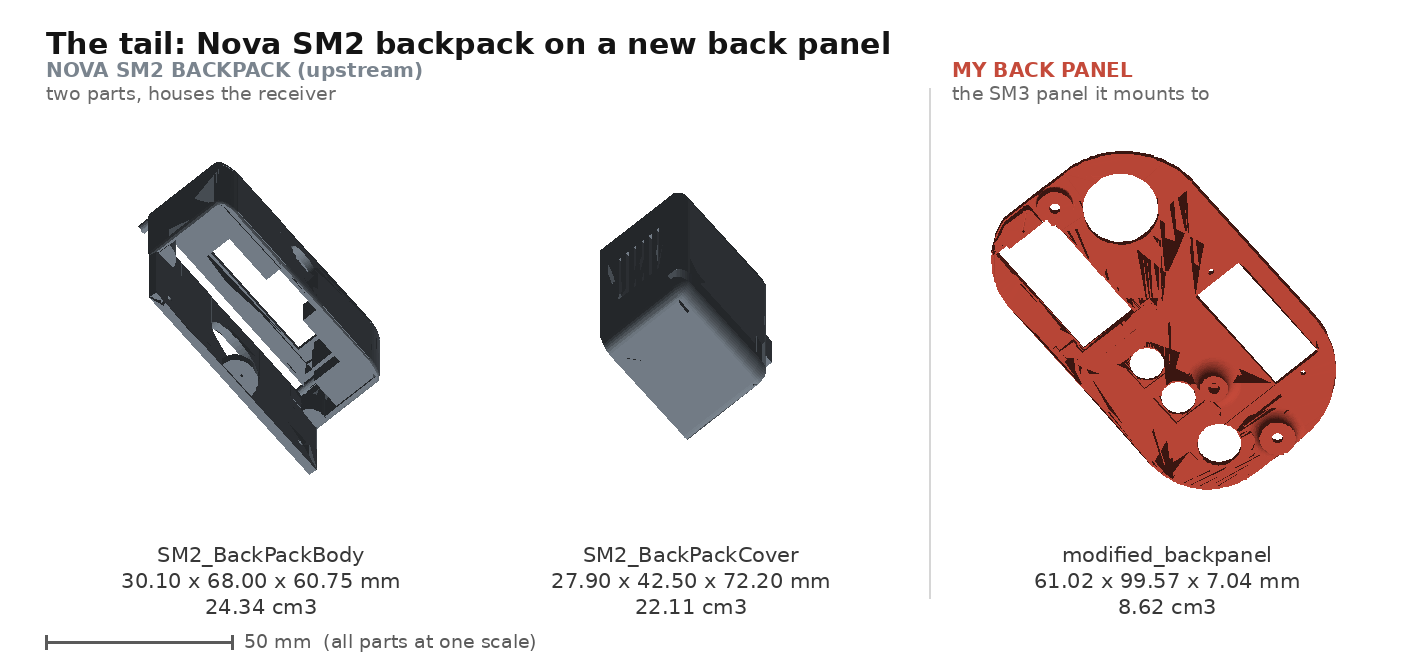
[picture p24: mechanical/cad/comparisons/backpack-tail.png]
Backpack and back panel


| Part | Whose | Envelope | Volume |
|---|---|---|---|
| `SM2_BackPackBody.stl` | upstream Nova SM2 | 30.10 x 68.00 x 60.75 mm | 24.34 cm3 |
| `SM2_BackPackCover.stl` | upstream Nova SM2 | 27.90 x 42.50 x 72.20 mm | 22.11 cm3 |
| `modified_backpanel.stl` | **mine** | 61.02 x 99.57 x 7.04 mm | 8.62 cm3 |

The two backpack parts are upstream geometry and are **not my work**. The back panel they
mount to is: at 7 mm thick it is essentially a flat plate, and its job is to carry the
backpack on the outside of the body while presenting a clean face on the inside.

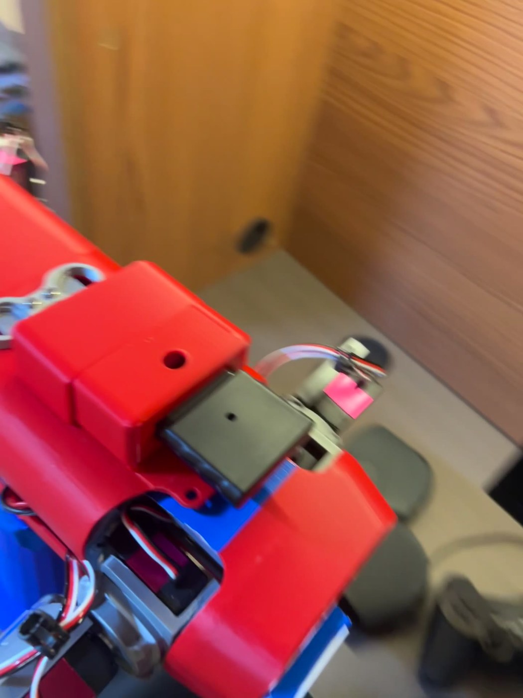
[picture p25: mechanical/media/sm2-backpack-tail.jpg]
The tail on the assembled robot


*The black module protruding from the top rear of the body is the ps2 remote receiver.*

**Fitting it was hand work, not CAD.** The mounting holes were **melted through with a
soldering iron (hehehe)** rather than printed or drilled. Brass **heat-set threaded inserts** were
melted into those holes with the same iron, and the assembly was secured with those and
nuts. That is not the elegant solution and I am not going to present it as one. I wanted a quick fix. This can be changed.

---

## Printing and first assembly

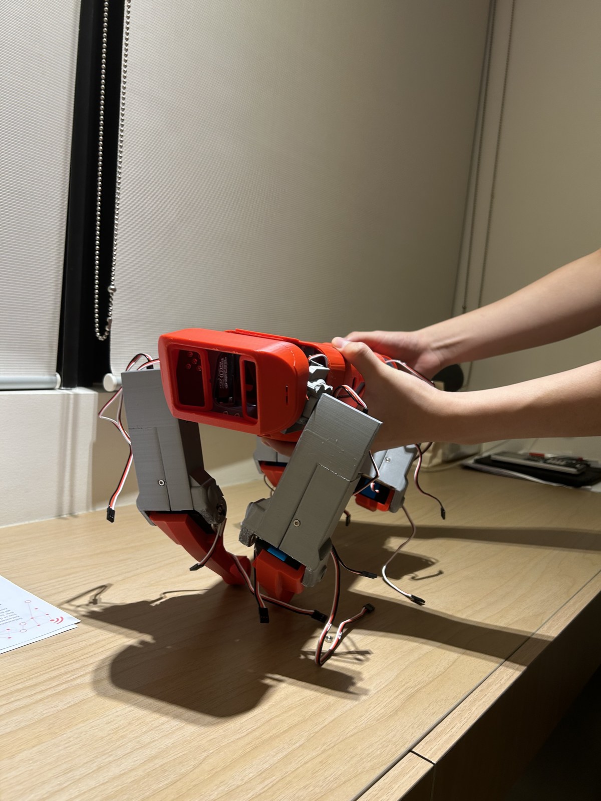
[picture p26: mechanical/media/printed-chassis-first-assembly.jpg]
First assembly of the printed chassis


*The printed structure assembled for the first time, before any electronics (except servos). Red tibias,
grey femurs and coax brackets.*

---

## Files

### [`cad/original/`](cad/original/): Chris Locke's, unmodified

Kept under upstream filenames and never edited in place. Only
the parts with a modified counterpart, or that I reused directly, are mirrored here. The
two `SM2_` files are the backpack, which comes from the earlier Nova SM2 rather than from
the SM3 set.

| File | Triangles | Envelope (mm) | Volume |
|---|---|---|---|
| `SM3_Frame_LeftCoax.stl` | 3,464 | 37.59 x 46.13 x 57.50 | 23.88 cm3 |
| `SM3_Frame_LeftFemur.stl` | 22,192 | 138.54 x 51.09 x 34.66 | 66.02 cm3 |
| `SM3_Cover_LeftFemur.stl` | 12,920 | 156.79 x 55.47 x 40.45 | 33.26 cm3 |
| `SM3_Frame_LeftTibia.stl` | 4,332 | 129.35 x 100.09 x 38.48 | 30.27 cm3 |
| `SM2_BackPackBody.stl` | 4,524 | 30.10 x 68.00 x 60.75 | 24.34 cm3 |
| `SM2_BackPackCover.stl` | 2,180 | 27.90 x 42.50 x 72.20 | 22.11 cm3 |

### [`cad/modified/`](cad/modified/): mine

Both the STL and the native SolidWorks part, so the geometry stays re-editable.

| File | Triangles | Envelope (mm) | Volume | Is |
|---|---|---|---|---|
| `modified_coax.stl` | 3,406 | 37.45 x 49.77 x 57.97 | 26.21 cm3 | hip bracket |
| `modified_femur_body-1.stl` | 5,370 | 147.13 x 68.49 x 35.66 | 90.73 cm3 | femur, part 1 |
| `modified_femur_body-2.stl` | 5,608 | 99.64 x 37.52 x 38.52 | 66.15 cm3 | femur, part 2 |
| `modified_femur_plate.stl` | 10,978 | 149.64 x 109.99 x 38.52 | 156.88 cm3 | both femur bodies, as printed |
| `modified_tibia.stl` | 3,032 | 36.02 x 155.10 x 56.84 | 83.94 cm3 | knee to foot, one piece |
| `modified_backpanel.stl` | 10,492 | 61.02 x 99.57 x 7.04 | 8.62 cm3 | back panel carrying the SM2 backpack |

The native SolidWorks parts are alongside them: `modified_coax.SLDPRT`,
`modified_femur_plate.SLDPRT` and `modified_tibia.SLDPRT`. These are the re-editable
versions; the STLs are exports.

### [`cad/modified/solidworks/`](cad/modified/solidworks/)

Screenshots of the models and their feature trees of modified parts.

| Screenshot | Document | Shows |
|---|---|---|
| `coax-solidworks-tree.png` | `coaxmodified_fixed` | `Imported1` at the top of the tree, then my sketches and extrudes on top of it |
| `femur-mirrored-pair.png` | `finalprintv67legs` | the femur bodies as a mirrored left/right pair |
| `femur-feature-tree.png` | `finalprintv67legs` | the same document's full feature list, roughly twenty-five operations |
| `tibia-solidworks.png` | `legbottom2` | the tibia, new knee enclosure above the original lower arm |

### [`cad/comparisons/`](cad/comparisons/)

`coax-comparison.png`, `coax-servo-pocket.png`, `femur-comparison.png`,
`tibia-comparison.png` and `backpack-tail.png`, rendered directly from the STL files above
at a single shared scale, with the measured numbers printed on the figure. Nothing here is drawn by hand and all of it regenerates from
the geometry alone.

---

## What is not documented here

A portfolio that only shows what went well is not worth much:

- **No dimensioned drawings.** These are rendered comparisons and measured envelopes, not a
  drawing package with tolerances.
- **No print settings or material record.** Layer height, infill, material and orientation
  were not logged, and I am not going to reconstruct them from memory.
- **No load analysis.** Parts were sized by judgement and iteration, not by FEA or by
  measured joint torque. The 35 kg.cm servo at the knee was chosen because the knee carries
  the most load, not from a calculation.
- **Only the left-side parts are archived here.** The right-side parts are mirrors, visible
  in the `finalprintv67legs` document but not exported separately into this set.

---

## Licence

`cad/original/` is Chris Locke's work under the upstream project's terms. `cad/modified/`
is derived from it and carries the same obligations. If you use either, credit
[novaspotmicro.com](https://novaspotmicro.com).

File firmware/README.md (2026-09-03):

# Nova SM3: Firmware

Nova SM3 is the firmware for a **Spot-Micro-class quadruped robot**: a twelve-servo
four-legged walker built around a Teensy 4.0 and an Arduino Nano. It walks, trots,
marches, sits, kneels, follows a person around a room using PIR sensors, and reports
what it is doing on a small colour display and a pair of RGB "eyes".

This directory holds the Arduino sketches. The leg redesign is in
[`../mechanical/`](../mechanical/README.md) and the wiring, power and bring-up work is in
[`../electronics/`](../electronics/README.md). The upstream project's home is
[novaspotmicro.com](https://novaspotmicro.com).

<- [back to the main README](../README.md)

---

## What Version 6.0 is

**Version 6.0 is a readability release.** It is version 5.1 reorganised and documented,
not rewritten. The robot behaves the same, the servo calibration is byte-for-byte
identical, and the gait tuning is untouched.

What changed is how the code reads:

| | v5.1 | v6.0 |
|---|---|---|
| Teensy sketch | one 6,390-line `.ino` | 12 tabs, largest 886 lines |
| Largest function | `ps2_check()`, 812 lines, 8 levels deep | `follow()`, 215 lines |
| `serial_command()` | 633 lines | 18-line dispatcher + 10 topic groups |
| `setup()` | 425 lines | 19 lines, one call per boot step |
| Nano `requestCallback()` | 264 lines | 27 lines + 2 handlers |
| Slave protocol | 85 undocumented strings like `"MQNOFzn"` | named constants in a shared header |
| Nano flash used | 91% | 83% |

Two genuine bugs were found and fixed along the way; both are listed under
[Behaviour changes](#behaviour-changes) and marked `BUGFIX (v6.0)` in the source.

Version 5.1 is left in place as `Nova-SM3_teensy-v5.1/` and `Nova-SM3_nano-v5.1/`.
If something misbehaves, those are the reference. Note that v5.1 already carries the
PS2 diagnostic reporter (`ps2_debug_report()` and the `ps2` / `ps2r` serial commands)
added during earlier bring-up work; v6.0 inherits it.

---

## The two boards

Nova runs on two microcontrollers connected over i²c.

```
        ┌──────────────────────────┐                ┌────────────────────────┐
        │  Teensy 4.0  -  MASTER   │      i²c       │  Arduino Nano - SLAVE  │
        │                          │◄──────────────►│                        │
        │  12 servos (PCA9685)     │  one command   │  SSD1331 OLED          │
        │  MPU6050 IMU             │  byte at a     │  4 NeoPixel "eyes"     │
        │  PS2 wireless remote     │  time          │  2 ultrasonic sensors  │
        │  3 PIR motion sensors    │                │  EEPROM settings       │
        │  current + battery sense │                │                        │
        │  DFPlayer Mini MP3       │                │                        │
        │  USB serial commands     │                │                        │
        └──────────────────────────┘                └────────────────────────┘
             does all the thinking                    owns only its own I/O
```

The Teensy makes every decision. The Nano makes none, it receives single-byte
commands and carries them out. **Every one of those bytes is named and documented in
`NovaSlaveProtocol.h`,** which is the single most useful file to read if you want to
understand how the two halves fit together.

The two sketches must be flashed as a matched pair.

---

## The interfaces

There is no single bus in this robot. Nearly every peripheral speaks something different,
and a good deal of the bring-up work was getting each one talking on its own terms.

| Interface | Where | What is on it |
|---|---|---|
| **I2C**, `Wire` | Teensy | PCA9685 servo driver at `0x40` |
| **I2C**, `Wire1` | Teensy, SDA2 17 / SCL2 16 | **shared**: the MPU6050 IMU at `0x68` *and* the Nano at address 1 |
| **PWM** | PCA9685 outward | 12 servos at `SERVO_FREQ` 60 Hz |
| **Bit-banged serial** | Teensy, pins 7/8/9/10 | the PS2 receiver |
| **UART** | Teensy, `SoftwareSerial` | DFPlayer MP3 module |
| **USB serial** | Teensy | the typed command interface |
| **SPI** | Nano | SSD1331 OLED |
| **Timed single wire** | Nano, pin 2 | 4 NeoPixels |
| **Pulse timing** | Nano, `NewPing` | 2 ultrasonic sensors |

Two of these are worth knowing about before you debug anything.

**The IMU and the slave share `Wire1`.** The Teensy's second I2C bus carries both the
MPU6050 and the entire master/slave conversation. They coexist on different addresses, but
they are not independent: a device holding that bus affects the other one.

**The PS2 protocol is bit-banged, not hardware SPI.** It resembles SPI, and it uses four
wires that look like SPI, but `PS2X_lib` drives clock, command and select **in software**,
toggling the pins directly:

```cpp
digitalWrite(_clk, HIGH);
// ...
digitalWrite(_clk, LOW);
```

That has consequences. The timing is produced by the CPU, so anything that blocks or
delays the loop can corrupt a read, which is part of why nothing in this firmware is
allowed to call `delay()` while the robot is running. It is also why `OE_PIN` is held high
through boot until the PS2 link is up: the PWM driver interferes with the receiver, and a
bit-banged protocol has no hardware peripheral to absorb that interference.

### Why PS2 and not the nRF24L01

The v5.2b board this build is based on, and upstream's newer firmware, are designed around
an **nRF24L01 plus a custom-built handheld remote**. Building that remote is a project in
itself: its own board, its own enclosure, its own firmware.

I did not want to build my own controller, so I did not. **The nRF24L01 was left
unpopulated and a PS2 receiver wired onto the PS2-COM header in its place**, which let me
use an off-the-shelf gamepad. Upstream's older versions drove the robot from a PS2
controller, so that code path already existed and was known to work.

The cost is that v6.0 is, as my own source header puts it, a "Frankenstein": v5.1's
structure with the older PS2 control path kept alive. The nRF footprint has to stay empty
because D9 and D10 are shared with it. See the
[electronics write-up](../electronics/README.md) for the wiring side of that decision.

---

## Directory layout

```
firmware/
├── README.md                     this file
├── CLAUDE.md                     notes for AI coding assistants
│
├── Nova-SM3_teensy-v6.0/         ← CURRENT master sketch (Teensy 4.0)
├── Nova-SM3_nano-v6.0/           ← CURRENT slave sketch  (Arduino Nano)
│
├── Nova-SM3_teensy-v5.1/         previous master, kept as reference
├── Nova-SM3_nano-v5.1/           previous slave, kept as reference
├── Nova-SM3_teensy-v5.0/         older master (no MP3 support)
├── Nova-SM3_teensy-v4.2/         Mega-era master
├── Nova-SM3_nano-v4.2/           Mega-era slave
│
├── Nova-SM3-calibrate/           bench sketch: measure servo home + limits
├── Tests/                        one small sketch per subsystem, for bring-up
└── Arduino Libraries/            vendored third-party libraries
```

Each version directory is a **complete, independent sketch**, not a patch on the one
before it. They are snapshots. A fix made in v6.0 does not propagate anywhere.

---

## Master sketch: `Nova-SM3_teensy-v6.0/`

Open `Nova-SM3_teensy-v6.0.ino` in the Arduino IDE and the rest appear as tabs.
They all compile together as one program, so a global declared in the main tab is
visible in every other one.

| File | Responsibility |
|---|---|
| `Nova-SM3_teensy-v6.0.ino` | **Start here.** Globals, `setup()`, `loop()`, the boot sequence, shutdown |
| `NovaConfig.h` | **The file you edit.** Debug flags, which hardware is fitted, the pin map |
| `NovaServos.h` | Per-robot servo calibration and the motion state arrays |
| `NovaSlaveProtocol.h` | Names for every byte sent to the Nano: shared with the slave sketch |
| `AsyncServo.h` | The non-blocking servo motion engine |
| `MPU6050_conf.h` | Register-level IMU driver (third-party, left as-is) |
| `pitches.h` | Musical note frequencies (stock Arduino file) |
| `Ps2Remote.ino` | Reading the remote and turning it into movement requests |
| `Sensors.ino` | PIR, ultrasonic, IMU, current draw, battery voltage |
| `ServoControl.ino` | The layer between movement routines and `AsyncServo` |
| `Poses.ino` | Named stances: stay, sit, crouch, lay, kneel, look left/right |
| `Motion.ino` | Body attitude: roll, pitch, yaw, axis wiggles |
| `Gaits.ino` | The walking gaits |
| `Sequences.ino` | Scripted multi-step routines and the sequencer |
| `SerialCommands.ino` | The typed command interface |
| `SlaveComms.ino` | The i²c conversation with the Nano |
| `Sound.ino` | Buzzer tunes and MP3 playback |
| `Util.ino` | Clamping, unit conversion, joint predicates |

### Where the main logic lives

Everything hangs off `loop()`, which does exactly three things on every pass and
**never blocks**:

```
loop()
 │
 ├─ 1. update_servos()          advance all 12 servos one PWM tick, if due
 │                              → AsyncServo::Update()  (AsyncServo.h)
 │
 ├─ 2. one movement routine     a chain of move_* flags selects AT MOST ONE
 │                              → step_march(), roll(), wake(), …
 │                                (Gaits.ino, Motion.ino, Sequences.ino)
 │
 └─ 3. poll each subsystem      each on its own millis() timer
                                → ps2_check(), serial_check(), pir_check(),
                                  get_mpu(), uss_check(), battery_check()
```

The single most important thing to understand about this codebase:

> **Movement routines do not move anything.** They set `targetPos[]` and
> `servoSpeed[]` for the servos they care about, and return immediately. The motion
> happens later, one tick at a time, inside `AsyncServo::Update()`.

That is why a routine that "does nothing" is almost always a movement flag that was
never set, or one that something else already cleared. It is also why nothing in the
sketch is allowed to call `delay()` while the robot is running.

### The four PS2 button sets

The remote has four modes, cycled with SELECT and tracked in `ps2_select`. Every
button means something different in each. If a control seems dead, check which set is
active first, this catches most "the remote is broken" reports.

| Set | Purpose |
|---|---|
| 1 | Walking and body attitude: roll, pitch, axis wiggles |
| 2 | Gait control and fixed poses: sit, kneel, crouch, lay |
| 3 | Kinematics: the sticks steer body position and yaw directly |
| 4 | Per-joint calibration jogging, for bench work |

Type `ps2` on the serial monitor to get a live report of button presses, stick values
and the current set.

---

## Slave sketch: `Nova-SM3_nano-v6.0/`

| File | Responsibility |
|---|---|
| `Nova-SM3_nano-v6.0.ino` | **Start here.** Globals, `setup()`, `loop()`, the two i²c handlers |
| `NovaSlaveProtocol.h` | The command bytes: **must stay identical to the master's copy** |
| `NovaBitmap.h` | The boot logo bitmap |
| `Display.ino` | Everything drawn on the OLED |
| `Leds.ino` | The NeoPixel eye animations |
| `Settings.ino` | EEPROM settings and the self-reset |

Two i²c interrupt handlers do all the work: `receiveEvent()` stores the incoming
byte, `requestCallback()` acts on it and returns a response. `loop()` only advances
the LED animation and the display, and watches the front-panel button.

The Nano keeps one piece of state that changes what a byte means, `serial_oled`.
When it is 0 an incoming byte is a system command (LEDs, sensors); when it is 1 it is
a display command. The byte `'X'` toggles it. On the master you never toggle it by
hand: use `rgb_request()` and `oled_request()`, which handle it for you.

---

## Building and flashing

There is no build system, test suite, or linter. These are plain Arduino sketches
and validation is physical, flash them and exercise the robot.

### Arduino IDE

1. Install the **Teensyduino** add-on for the Teensy 4.0.
2. Point the sketchbook library path at `Arduino Libraries/`, or install the
   equivalents through Library Manager.
3. Install **DFRobotDFPlayerMini** through Library Manager. It is *not* vendored.
   (`Arduino Libraries/DFRobot_DF1201S.zip` is for the DFPlayer Mini **Pro**, a
   different module with a different API.)
4. Open the sketch, select the board, Verify, Upload.

### arduino-cli

```bash
# master
arduino-cli compile --fqbn teensy:avr:teensy40 \
    --libraries "Arduino Libraries" Nova-SM3_teensy-v6.0

# slave
arduino-cli compile --fqbn arduino:avr:nano \
    --libraries "Arduino Libraries" Nova-SM3_nano-v6.0
```

Both compile clean as of this release. Current usage:

* **Teensy 4.0**: 121 KB flash of 1.9 MB available, 29 KB RAM1. Plenty of room.
* **Arduino Nano**: 83% of flash, 48% of RAM. **Very little room.** Check the
  compiler's final report before adding anything to the slave.

---

## Things you need to know before running it

**Set every debug flag in `NovaConfig.h` to 0 before running Nova untethered.**
On a Teensy, printing to a serial port that nothing is listening on will stall the
board, and Nova will appear completely dead. This is the single most common way to
lose an afternoon on this project.

**The Teensy 4.0 is not 5V tolerant.** Every input must stay at or below 3.3V. In
particular the PS2 receiver must be powered from 3.3V, powering it from 5V will
damage the Teensy through its DATA line.

**`OE_PIN` is active LOW.** Driving it LOW *enables* the servos. It is held HIGH
through boot until the PS2 link is up, because the PWM driver interferes with the
receiver and would otherwise make the robot lurch on power-up. Servo output arms
roughly a second after boot.

**`servoHome[]` and `servoLimit[]` in `NovaServos.h` are physical measurements** of
one assembled robot, in raw PWM ticks. They are not tunable constants. If a leg sits
wrong, re-measure with `Nova-SM3-calibrate/` rather than nudging the numbers. They
are only meaningful at the `SERVO_FREQ` / `OSCIL_FREQ` set in `NovaConfig.h`, which
is why both carry a "do not change once calibrated" warning.

**`servoLimit[]` pairs are ordered by leg direction, not numerically.** For the left
legs the first value is the *larger* number, because those servos are mirrored. Any
code comparing against them has to check which way round the pair is, see
`limit_target()`.

**Speed is a delay.** `servoSpeed[]` is the number of milliseconds between one PWM
tick and the next, so a *bigger* number means a *slower* servo. This is why
`max_spd` (1.0) is numerically smaller than `min_spd` (96.0).

**`AMP_PIN` and `BATT_MONITOR` are the same analog pin (A1).** This robot cannot
read current and battery voltage at the same time. Do not enable both `amp_active`
and `batt_active` without rewiring.

**`NovaSlaveProtocol.h` exists twice**, once in each sketch folder. The Arduino IDE
cannot share a header between two sketch folders. The two copies must be kept
identical or the boards will disagree about what a byte means.

---

## Author / Modification Notes

**Original author: Chris Locke** (<cguweb@gmail.com>), Nova SM3 is his design and
his code, including the mechanical design, the gait development, the servo motion
engine and the master/slave architecture. Project home:
[novaspotmicro.com](https://novaspotmicro.com) ·
[GitHub](https://github.com/cguweb-com/Arduino-Projects/tree/main/Nova-SM3) ·
[Thingiverse](https://www.thingiverse.com/thing:4767006) ·
[Instructables](https://www.instructables.com/Nova-Spot-Micro-a-Spot-Mini-Clone/)

**Version 6.0 modified by: Jeremy Aidan Yu**, with assistance from **Claude Code** (Anthropic).

Version 6.0 makes no claim on the design or the behaviour of the robot. The work in
this release is confined to structure, naming and documentation. The original code
was written as a personal project under active hardware development, with the
author's own notes and open questions left in place deliberately, those notes are
preserved here, and the DEV NOTE comments marking unfinished work are still in the
source where he left them.

---

## What changed in Version 6.0, and why

Every change below is a real edit, verified by compiling both sketches for their
actual target boards after each step. Where a change was purely mechanical, the
compiler's reported flash and RAM usage was compared before and after: the slave
protocol renaming and the file split both produced **byte-identical output**, which
is about as strong a guarantee as is available without hardware.

### Organisation

**Split the 6,390-line master sketch into 12 tabs by topic.** A single file that
large cannot be navigated; you scroll for it. The tabs follow the section banners
the original author had already put in the file, so the grouping is his, not an
invention. Arduino compiles all tabs as one program, so this changed nothing about
how the code works, and was verified by identical compiler output before and after.

**Split the 1,265-line slave sketch into four source files and two headers**, and
moved the 64-line boot logo
out of the middle of the variable declarations into `NovaBitmap.h`.

**Extracted `NovaConfig.h`.** Debug flags, "what hardware is fitted" flags and every
pin `#define` were scattered through 380 lines of globals. They are now in one file
with a full pin-map table, because they are the only things most people ever edit.

**Broke up the three functions that were 29% of the file.**

* `ps2_check()` (812 lines, eight levels of nesting, 57 tests of `ps2_select`) is
  now a 25-line dispatcher plus one handler per button group. The structure was
  always *[which button] × [which of four sets]*; it was just flattened into one
  chain.
* `serial_command()` (633 lines of chained string comparison) is now an 18-line
  dispatcher over ten topic groups, each returning whether it recognised the
  command. First-match-wins ordering is preserved exactly.
* `setup()` (425 lines) is now 19 lines, one call per boot step, so the order the
  hardware comes up in is readable at a glance.

**Split the slave's `requestCallback()`** (264 lines) into an OLED-command handler
and a system-command handler.

### Naming and magic values

**Named every byte of the master/slave protocol.** This was the single biggest
obstacle to understanding the codebase. Calls looked like this:

```cpp
rgb_request((char*)"MONRDn");     // ...meaning what?
oled_request((char*)"9n");
```

and could only be decoded by reverse-engineering a 264-line switch on the other
board. There are now named constants in `NovaSlaveProtocol.h`, shared by both
sketches, and because they are string literals they concatenate at compile time, so
the call sites cost exactly the same flash they did before:

```cpp
rgb_request(RGB_LEFT RGB_RED  RGB_RIGHT RGB_YELLOW  RGB_SPEED_30 RGB_PATTERN_BLINK);
oled_request(OLED_BATTERY_LEVEL_9 OLED_BATTERY_GAUGE);
```

All 125 call sites were converted by script rather than by hand, so no string was
mistranscribed.

**Named the columns of the multi-dimensional motion arrays.** `servoRamp[id][5]` and
`servoSweep[id][2]` are now `servoRamp[id][RAMP_DOWN_SPEED]` and
`servoSweep[id][SWEEP_DIR]`. Eight ramp columns and five sweep columns were
previously bare indexes that had to be traced through `AsyncServo` to interpret.

**Replaced ASCII codes with the characters they stand for.** The slave's display
dispatch was written as `if (cmd == 97) { //a` … `else if (cmd == 119) { //w`, so the
reader had to trust 23 hand-written comments. It now compares against the protocol
constants directly.

**Renamed `AsyncServo::pwmBoard` to `pwmPin`.** It holds a PCA9685 *channel* number,
not a board id, and it carried a copy-pasted comment claiming it was the pulse
increment. Three things with three different meanings under one name.

**Corrected several comments that described something other than what the code did**,
including the `servoSweep` column list (it named a nonexistent "sweep type" and
described a cycle counter as milliseconds) and the note about `pinMode` ordering in
the servo test sketch.

### Removing duplication

**Extracted `set_sweep()`.** The seven-line block that arms a servo to sweep between
two positions appeared **67 times**. It is now one documented function and 67 call
sites, which took about 260 lines of near-identical code out of the movement
routines and makes the actual differences between gaits visible.

**Extracted the ramp interpolation in `AsyncServo`.** A 35-line block was duplicated
character-for-character between the move path and the sweep path, and was verified identical
before extracting, so a future fix to one can no longer miss the other.

**Collapsed the PS2 joint-jogging code.** Twelve copies of an 11-line "nudge this
joint by one tick" block became twelve one-line calls to `ps2_jog_joint()`.

**Table-driven the slave's command decoding.** The RGB commands arrive as four
contiguous blocks of bytes (pattern, repeat count, step interval, colour), so each
block is now a range test and a small `PROGMEM` lookup table instead of a `case` per
byte. Eight near-identical colour cases became one.

**Table-driven the battery gauge.** 111 lines of `fillRect` calls across ten
if/else branches were, on inspection, a 10×5 table of bar heights and colours where
every bar sits on the same baseline. It is now that table plus a five-iteration loop.
The ten voltage comparisons it used to make all resolved to "which level is it",
since the voltage being compared came from the same array, so the level indexes the
table directly.

**Table-driven the radar grid.** 32 hand-written `drawLine` calls became two short
loops over the gap positions.

**Table-driven the boot report.** 84 lines of "print a name, toggle the LED, wait"
became a table of subsystems and two loops.

Together these are the reason the Nano's flash use fell from **91% to 83%**. The
duplication was real, and it was costing space on the board that had none to spare.

### Documentation

**Rewrote the header of every file** to say what the file is for, what board it
targets, and how it fits with the others.

**Documented the things that surprise people**, at the point where they surprise
them: that speed is a delay so bigger is slower; that `OE_PIN` is active low; that
`servoLimit` pairs are direction-ordered rather than numerically ordered; that the
PWM channels skip 3, 7, 11 and 15 so the servo index is not the channel number; that
`AMP_PIN` and `BATT_MONITOR` are the same physical pin; that any debug flag left set
will stop the Teensy booting untethered.

**Explained the `plotter` flag.** Roughly 90 `Serial.print` calls were wrapped in
`if (!plotter)` with no explanation anywhere in the project. It suppresses
human-readable output so the remaining numeric output can be fed to the Arduino
Serial Plotter, which only understands `label:value` lines.

**Rewrote the serial help screen.** The old one was hand-aligned with tab
characters and had drifted out of step with the code: `ms+` and `ms-` were described
with each other's behaviour, a row labelled `s-` actually documented `l-`, and two
commands (`stl`, `str`) were listed that do not exist. It is now generated from a
table grouped to match the command handlers, and lists everything the sketch accepts.

### Dead and confusing code

* Removed a `test_loops` soak-test block wired into the middle of `step_march()`.
  Its trigger variable was initialised to 0 and never set anywhere, so it could not
  run; it also carried its own broken indentation.
* Removed eleven global variables that were declared and never read. Two of them,
  `pattern_int` and `pattern_cnt`, shadowed the names of variables on the *slave*
  that are load-bearing, which is actively misleading.
* Removed `save_ep_data()` on the slave, which was declared, defined and never
  called. The EEPROM write it duplicated still happens inline in the reboot
  handlers, and `load_ep_data()` now documents why the other four settings are read
  but never written.
* Removed a system-mode `'c'` command on the slave that set `oled_command = 9997`.
  The value was truncated to a meaningless byte on the way to `oled_check()`, and
  the master never sends `'c'` in that mode anyway.
* Simplified a loop in `run_sequence()` that wrote `servoSequence[0]`,
  `servoSequence[l]`, `servoSequence[2]` and `servoSequence[3]` on every iteration.
  It cleared all four legs by accident; clearing `servoSequence[l]` does the same
  thing on purpose.
* Removed empty `if` branches that existed only to be fallen through, and inverted
  one `if (…) { } else { … }` that read backwards.
* Renamed an inner loop variable that shadowed the outer sequence index in
  `delay_sequences()`.
* Reordered `delay_sequences()`'s sixteen branches into numeric order and made them
  a `switch`. Routine 13 was previously listed between 2 and 3, which is easy to
  miss when you are looking for it. This also removed a dangling `if (debug1)` whose
  body had been commented out, leaving it silently attached to the next statement.

### Behaviour changes

Two, both fixes for real defects found while reading:

1. **`Ps2Remote.ino`: releasing R1 never stopped the body roll.** The release
   handler for the R1 button tested `PSB_R2` instead of `PSB_R1`. Letting go of R1
   left `move_roll_body` set, so the body kept rolling until something else called
   `set_stop()`; letting go of R2 cleared it instead, stealing R2's own release.
   Every other trigger clears the flag its own button set. Marked
   `BUGFIX (v6.0)` in the source.

2. **`Nova-SM3_nano-v6.0.ino`: `get_distance()` printed with debugging off.** Of
   three consecutive `Serial.print` calls, only the first was guarded by `debug1`;
   the other two ran on every ultrasonic reading. All three are now inside the
   guard. Marked `BUGFIX (v6.0)` in the source.

One further, trivial difference: `serial_command()` now returns early on an empty
command instead of falling through to the "not a valid command input" message, so
typing a bare comma no longer produces an error line. The old test was `if (cmd)`,
which on an Arduino `String` is always true and reads as though it checks for
emptiness when it does not.

### What was deliberately left alone

* **`servoHome[]`, `servoLimit[]`, `SERVO_FREQ`, `OSCIL_FREQ`.** Physical
  calibration of one specific robot. Verified byte-for-byte identical to v5.1.
* **The gait mathematics.** `step_march()`, `step_forward()`, `wman()` and
  `funplay()` are full of hand-tuned multipliers arrived at by trial on real
  hardware. They were commented, not restructured. Renaming a variable there risks
  the tuning for no functional gain. This has no Inverse Kinematics.
* **`MPU6050_conf.h`.** Third-party register-level driver tracking a published
  datasheet. Reformatting it would make it impossible to diff against upstream. Only
  a header comment was added, explaining that and pointing at where the sensor fusion
  actually happens.
* **`pitches.h`.** The stock Arduino note table.
* **The `move_*` flag architecture.** Fifty-two booleans, of which exactly one may
  be true, is really an enum, but converting it touches every movement routine and
  every stop path at once. It is documented instead, including the warning that a new
  flag must also be cleared in `set_stop_active()`. This is the most worthwhile
  remaining change, and the right time for it is when the flags start fighting each
  other.
* **A logging wrapper for the `plotter` guard.** Replacing ~90 instances of
  `if (!plotter) Serial.println(…)` with a helper was considered and rejected: the
  guard is uniform and mechanical, and a reader only needs to learn it once. The flag
  is documented at its declaration instead.
* **Older version directories** (`v5.1`, `v5.0`, `v4.2`) and the vendored
  `Arduino Libraries/`.

### Worth reviewing on hardware

Everything here compiles for the real target boards, and the mechanical
transformations were verified against compiler output. But this is firmware, and
nothing below has been run on a robot:

* **The R1 release fix** changes what the remote does. Confirm in button set 1 that
  holding R1 rolls the body and releasing it stops.
* **The battery gauge rewrite** replaced a voltage cascade with a table lookup. The
  substitution is provable on paper, but stepping the level through 0-9 with the
  `batt` serial command is a five-minute check worth doing.
* **The `set_sweep()` extraction** touched 67 call sites across every movement
  routine. Each was converted mechanically, but exercising the sweeps (`st`, `sf`,
  `sc`, `rst`, `rsf`) and the body movements (`roll`, `pitch`, `rollb`, `pitchb`,
  `x`, `y`) covers essentially all of them.
* **The `AsyncServo` ramp extraction** is the highest-consequence change in the
  release, since that code runs for every servo on every pass. The two blocks it
  merged were verified character-identical first, but ramping is worth watching:
  `rst` and `rsf` exercise it directly.
* **The Nano's flash headroom** improved, but it remains the constrained board.

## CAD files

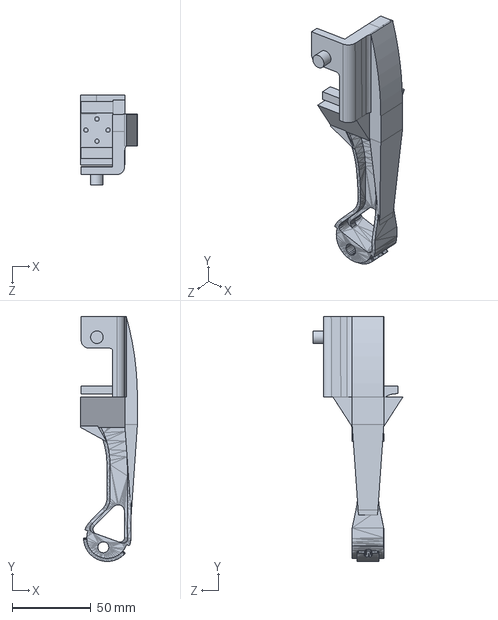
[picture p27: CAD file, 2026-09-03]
mechanical/cad/modified/modified_tibia.SLDPRT
36.0 x 155.1 x 56.8 mm

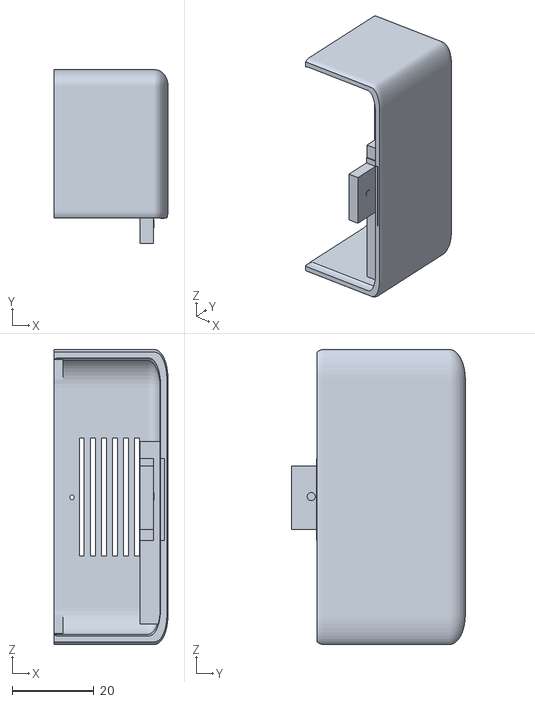
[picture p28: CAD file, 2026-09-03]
mechanical/cad/original/SM2_BackPackCover.stl
27.9 x 42.5 x 72.2

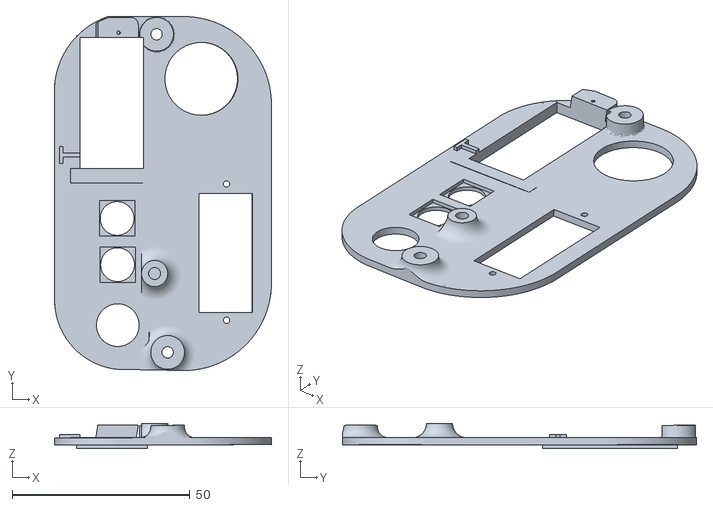
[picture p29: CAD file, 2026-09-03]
mechanical/cad/modified/modified_backpanel.stl
61.0 x 99.6 x 7.04

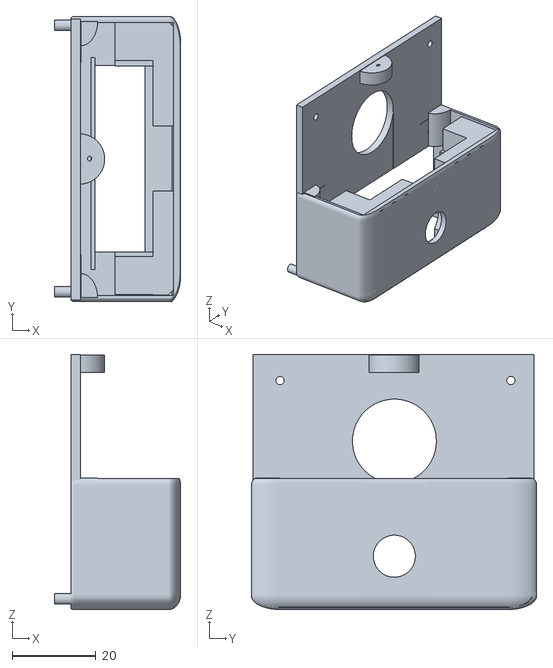
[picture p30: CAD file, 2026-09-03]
mechanical/cad/original/SM2_BackPackBody.stl
30.1 x 68.0 x 60.8

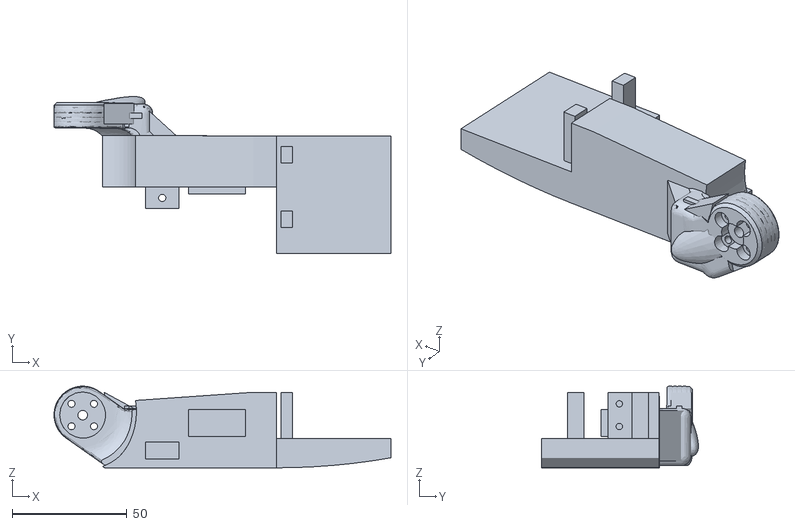
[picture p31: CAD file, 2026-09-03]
mechanical/cad/modified/modified_femur_body-1.stl
147.1 x 68.5 x 35.7

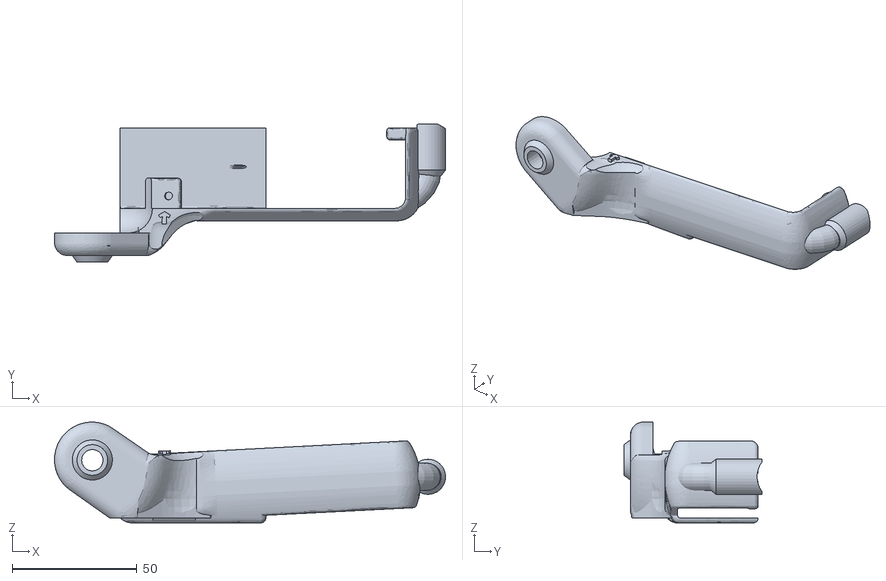
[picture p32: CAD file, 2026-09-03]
mechanical/cad/original/SM3_Cover_LeftFemur.stl
156.8 x 55.5 x 40.4

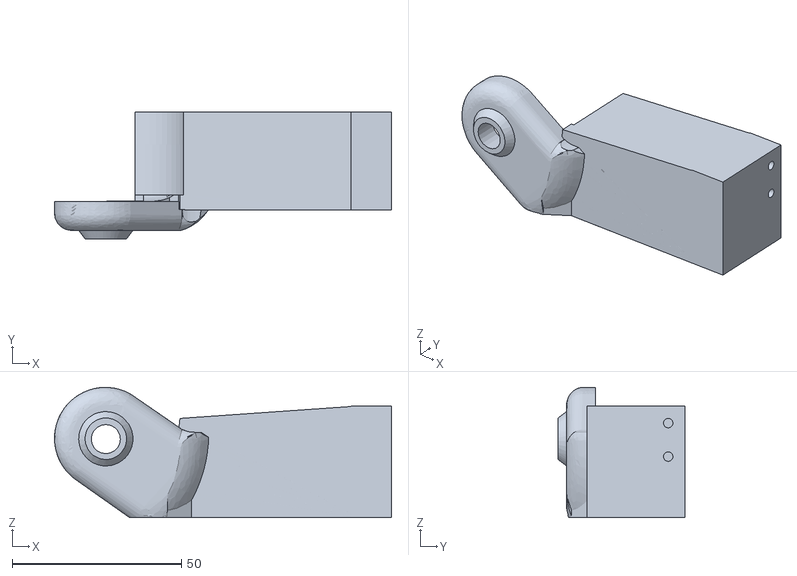
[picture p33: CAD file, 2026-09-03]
mechanical/cad/modified/modified_femur_body-2.stl
99.6 x 37.5 x 38.5

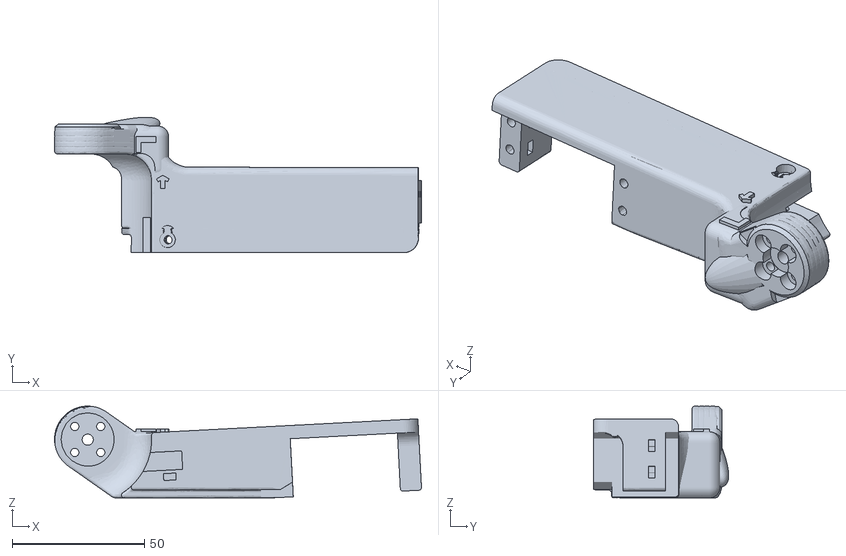
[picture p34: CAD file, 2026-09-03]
mechanical/cad/original/SM3_Frame_LeftFemur.stl
138.5 x 51.1 x 34.7

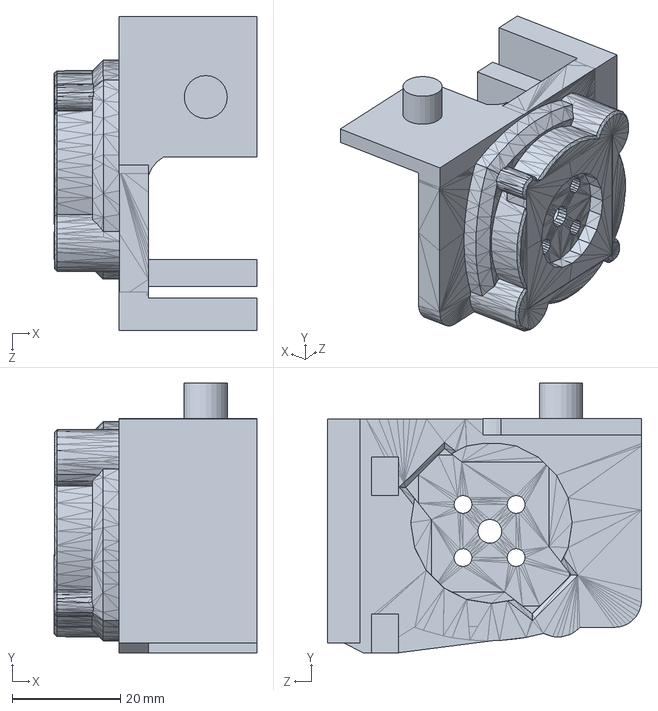
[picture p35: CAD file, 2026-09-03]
mechanical/cad/modified/modified_coax.SLDPRT
37.4 x 49.8 x 58.0 mm

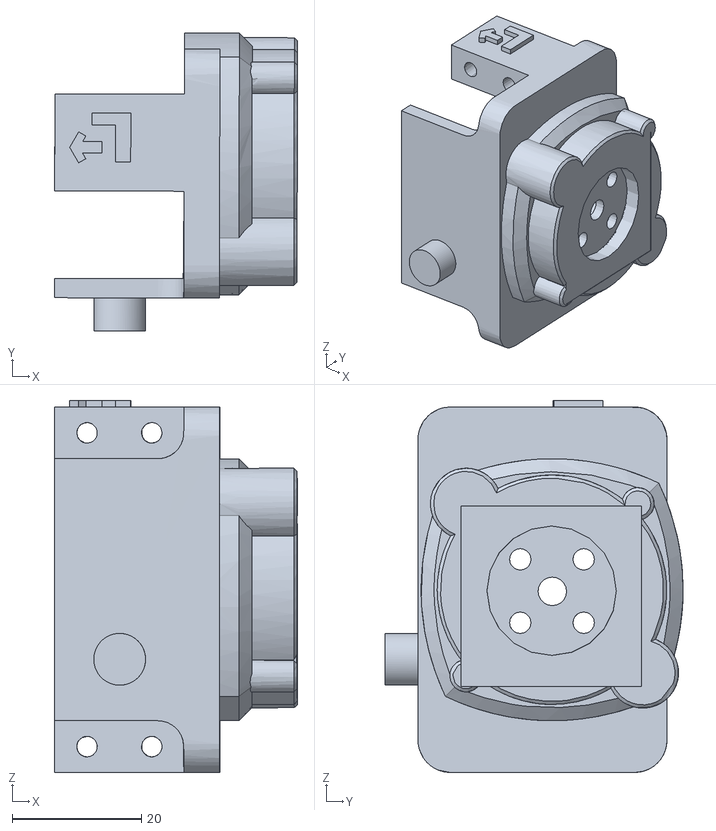
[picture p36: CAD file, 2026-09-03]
mechanical/cad/original/SM3_Frame_LeftCoax.stl
37.6 x 46.1 x 57.5

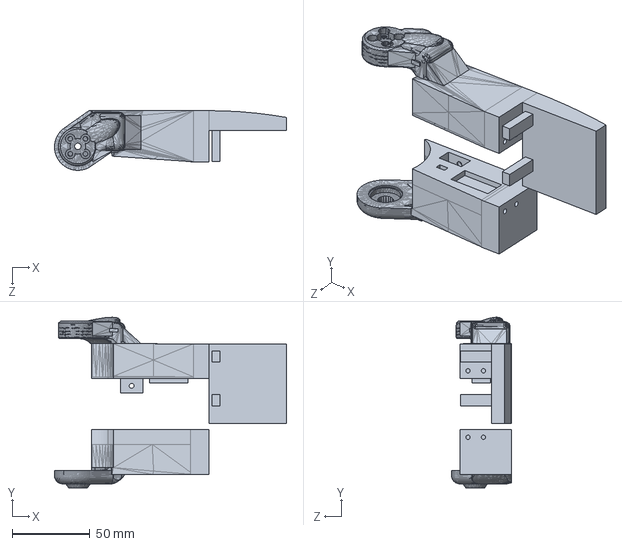
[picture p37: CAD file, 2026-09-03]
mechanical/cad/modified/modified_femur_plate.SLDPRT
149.6 x 110.0 x 38.5 mm

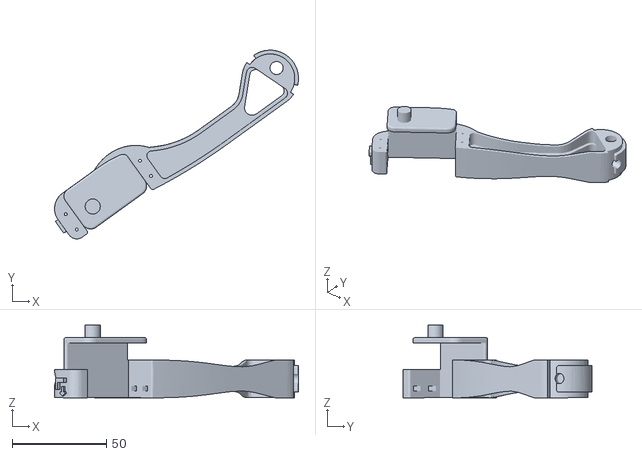
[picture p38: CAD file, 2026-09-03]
mechanical/cad/original/SM3_Frame_LeftTibia.stl
129.3 x 100.1 x 38.5

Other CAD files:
mechanical/cad/modified/modified_coax.stl
mechanical/cad/modified/modified_femur_plate.stl
mechanical/cad/modified/modified_tibia.stl

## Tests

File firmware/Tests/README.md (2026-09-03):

# Nova SM3: peripheral bench tests

Standalone, single-purpose sketches for isolating one piece of hardware at a
time. Each one is independent: flash it, confirm that subsystem works, move on.
None of them include `NovaServos.h`, `AsyncServo.h`, or any other main-sketch
file, so a pass here proves *wiring and hardware*, not the main firmware.

Pin assignments are copied from `Nova-SM3_teensy-v5.0` and `Nova-SM3_nano-v5.1`.
If you change a pin in the main sketches, change it here too or these stop
being a valid reference.

## Which board

| Sketch | Board | Peripheral |
|---|---|---|
| `Test_MPU6050` | Teensy 4.0 | MPU6050 IMU on `Wire1` (SDA2 17 / SCL2 16, addr 0x68) |
| `Test_PWM_Servos` | Teensy 4.0 | PCA9685 @ 0x40 + 12 servos, OE pin 3 |
| `Test_PIR` | Teensy 4.0 | 3× PIR (front 4, left 5, right 6) |
| `Test_PS2` | Teensy 4.0 | PS2 receiver (DAT 7, CMD 8, SEL 9, CLK 10) |
| `Test_MP3` | Teensy 4.0 | DFPlayer Mini (RX 0, TX 1, vol pot 20) |
| `Test_Ultrasonic` | Arduino Nano | 2× HC-SR04 (L 7/6, R 5/4) |
| `Test_OLED` | Arduino Nano | SSD1331 96×64 SPI (13/11/10/9/8) |
| `Test_NeoPixel` | Arduino Nano | 4× WS2812 eyes (pin 2) + brightness pot A3 |

Set the correct board in the IDE before uploading, the Teensy sketches will
not compile for a Nano and vice versa.

## Libraries

Point the IDE at `../Arduino Libraries/`, or:

```
arduino-cli compile --fqbn <fqbn> --libraries "../Arduino Libraries" Test_MPU6050
```

Everything is vendored **except** `DFRobotDFPlayerMini` (needed by `Test_MP3`),
which you must install via Library Manager. The vendored `DFRobot_DF1201S.zip`
is for the DFPlayer Mini **Pro**, a different module with a different API.

## Suggested order

Work outward from the things everything else depends on:

1. **`Test_MPU6050`**: also scans `Wire1`, so it doubles as an I²C bus check.
2. **`Test_PWM_Servos`**: scans the default `Wire` bus (should find `0x40`,
   and `0x01` if the Nano is powered). Confirms the master↔slave link exists
   before you trust either side.
3. **`Test_PS2`**, **`Test_PIR`**, **`Test_MP3`**: remaining Teensy peripherals.
4. **`Test_OLED`**, **`Test_NeoPixel`**, **`Test_Ultrasonic`**: Nano side.

## ⚠️ Before running `Test_PWM_Servos`

- **Put the robot on a stand with the legs hanging free.**
- Output is disabled at boot (`OE` held HIGH). Nothing moves until you type `e`.
- All moves are clamped to `servoLimit[]` from `NovaServos.h`.
- Note those limit pairs are `{min,max}` in *leg* direction, not numeric order
  (e.g. `LFF` is `{537,207}`), so the sketch clamps against the numeric lo/hi.
- The real thing this test catches: `servoSetup[]` maps servos to PCA9685
  channels 0,1,2 / 4,5,6 / 8,9,10 / 12,13,14, channels 3, 7, 11, 15 are
  deliberately skipped. A mis-wire produces **no error**, just the wrong joint
  moving. Jog each servo and confirm the expected joint responds.

## Serial

All sketches use **115200 baud**. Teensy sketches wait up to 5s for a serial
connection then continue regardless, so they won't hang if run untethered, unlike the main sketch, which will not boot without serial if any `debug` flag
is set.

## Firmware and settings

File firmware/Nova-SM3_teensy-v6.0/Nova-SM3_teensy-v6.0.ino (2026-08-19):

/*
 *   NovaSM3 - a Spot-Mini Micro clone
 *   Version: 6.0
 *   Version Date: 2026-08-19
 *
 *   TARGET BOARD: Teensy 4.0  --  this is the MASTER controller.
 *   Its partner is Nova-SM3_nano-v6.0, the slave that owns the display,
 *   the RGB eyes and the ultrasonic sensors.
 *
 *   Original Author:  Chris Locke - cguweb@gmail.com
 *   Nova's website:  https://novaspotmicro.com
 *   GitHub Project:  https://github.com/cguweb-com/Arduino-Projects/tree/main/Nova-SM3
 *   YouTube Playlist:  https://www.youtube.com/watch?v=00PkTcGWPvo&list=PLcOZNHwM_I2a3YZKf8FtUjJneKGXCfduk
 *
 *   Version 6.0 is a readability pass over version 5.1 by Jeremy, with
 *   Claude Code. Behaviour is unchanged apart from one documented bug fix
 *   (see the BUGFIX note in ps2_triggers). See README.md for the full list.
 *   
 *   BIG NOTE FROM JEREMY: TECHNICALLY FIRMWARE IS a Frankenstein not based strictly on 5.1....
 *   OLD Versions use ps2 remote control code, new ones use nRF Module and custom remote control
 *   I was too lazy to build a whole remote from scratch, so I used older versions as context for claude code.
 *   Since it uses the ps2 controller instead of nRFModule and a custom remote.
 *
 *   HOW THIS SKETCH IS ORGANISED
 *   ----------------------------
 *   The sketch is split across several tabs. Open them in the Arduino IDE and
 *   they all compile together as one program:
 *
 *     Nova-SM3_teensy-v6.0.ino   globals, setup(), loop()   <- start here
 *     NovaConfig.h               debug flags, fitted hardware, pin map
 *     NovaServos.h               per-robot servo calibration - do not guess at these
 *     NovaSlaveProtocol.h        names for the bytes sent to the Nano
 *     AsyncServo.h               the non-blocking servo motion engine
 *     MPU6050_conf.h             low-level IMU driver
 *     pitches.h                  musical note frequencies
 *     Ps2Remote.ino              reading the remote and turning it into moves
 *     Sensors.ino                PIR, ultrasonic, IMU, current and battery
 *     Poses.ino                  named stances and the servo-state helpers
 *     Motion.ino                 body attitude: roll, pitch, yaw, axis wiggles
 *     Gaits.ino                  the walking gaits
 *     Sequences.ino              scripted multi-step routines and the sequencer
 *     SerialCommands.ino         the typed command interface
 *     SlaveComms.ino             i2c conversation with the Nano
 *     Sound.ino                  buzzer tunes and MP3 playback
 *     Util.ino                   small shared helpers
 *
 *
 *   HOW IT RUNS
 *   -----------
 *   Nothing in this sketch blocks once it is running. loop() does three
 *   things, in this order, on every single pass:
 *
 *     1. update_servos()  - advance every servo one pwm tick towards its
 *                           target, if its own speed timer says it is due
 *     2. one movement     - a chain of move_* flags picks at most ONE
 *                           movement routine to advance this pass
 *     3. poll subsystems  - remote, serial, sensors, each on its own timer
 *
 *   Movement routines never loop or delay. They set targetPos[] and
 *   servoSpeed[] and return; the motion happens later inside AsyncServo.
 *   That is why a routine that "does nothing" is usually a movement flag
 *   that was never set, or one that something else already cleared.
 *
 *
 *   BEFORE YOU RUN IT
 *   -----------------
 *   Set every debug flag in NovaConfig.h to 0 before running Nova untethered.
 *   On a Teensy, printing to a serial port with nothing attached will stall
 *   the board and Nova will appear dead.
 *
 *
 *   KNOWN ISSUES carried over from 5.1
 *   ----------------------------------
 *      the IMU is not as smooth on the Teensy as it was on the Mega
 *      ramping: interrupting a ramp leaves the servo at the interrupted speed
 *      PIR sensitivity is too high at close range (12-24 inches)
 *      integrating IMU data into the movements is still unfinished
 *      the MP3 volume potentiometer on the switch panel is not wired up
 *
 *   Comments marked DEV NOTE mark unfinished work carried over from 5.1.
*/

//build configuration: debug flags, fitted hardware, and the pin map.
//This is the file to edit when changing what is enabled or how it is wired.
#include "NovaConfig.h"

//include supporting libraries
#include <Wire.h>
#include <PS2X_lib.h>
#include <Adafruit_PWMServoDriver.h>
#include <T4_PowerButton.h>
#include "SoftwareSerial.h"
#include "DFRobotDFPlayerMini.h"

//named constants for every byte sent to the Nano slave over i2c.
//included early so the RGB_* / OLED_* macros are defined before first use.
#include "NovaSlaveProtocol.h"

//one row of the serial help screen. Declared up here because the Arduino
//builder generates function prototypes near the top of the sketch, so any
//type used in a function signature must already be visible at this point.
struct HelpRow { const char* input; const char* what; };

/*
   =======================================================
   GLOBAL STATE

   Everything below is runtime state, grouped by the subsystem that owns it.
   Configuration - what is fitted, what is wired where, how much is printed -
   lives in NovaConfig.h instead.

   Two naming conventions run through all of it:
     lastXxxUpdate / xxxInterval   a millis() timer pair polled from loop()
     move_xxx                      a flag that selects a movement routine
   =======================================================
*/

/*
   -------------------------------------------------------
   Servo driver and speed
    :SPEED IS A DELAY. servoSpeed is the number of milliseconds between one
    :pwm tick and the next, so a BIGGER number means a SLOWER servo. That is
    :why min_spd (96) is numerically larger than max_spd (1).
   -------------------------------------------------------
*/
Adafruit_PWMServoDriver pwm1 = Adafruit_PWMServoDriver(0x40);
byte pwm_oe = 0;                  //1 once servo output has been enabled - see ps2_check()

const float min_spd = 96.0;       //slowest allowed: the longest gap between ticks
const float max_spd = 1.0;        //fastest allowed: the shortest gap between ticks
float default_spd = 13.0;         //speed restored when a routine finishes
float spd = default_spd;          //current global speed
float spd_prev = default_spd;     //saved across a routine that changes speed temporarily

//spd_factor scales the per-servo speeds inside the movement routines, so that
//raising the global speed speeds up a whole gait proportionally. It is
//recalculated from spd by set_speed().
float spd_factor = 1.0;
const float min_spd_factor = 5.0;
const float max_spd_factor = 0.5;

//per-joint speeds used by the generic sequencer, set by whichever routine is running
float spd_c;                      //coxa
float spd_f;                      //femur
float spd_t;                      //tibia

//steering input, in the -22..22 range the sticks are mapped into
float x_dir = 0;                  //+right / -left
float y_dir = 0;                  //+forward / -backward
float z_dir = 0;                  //+up / -down (ride height)

//acceleration / deceleration, applied by set_ramp()
byte use_ramp = 0;                //nothing ramps unless this is set
float ramp_dist = 0.20;           //fraction of the travel spent ramping at each end
                                  //(0.20 = accelerate over the first 20%, decelerate over the last 20%)
float ramp_spd = 5.00;            //how much slower than cruising speed a ramp starts


/*
   -------------------------------------------------------
   DFPlayer Mini MP3 module
    :tracks are played by number, so the SD card contents matter:
    :  1.saber   2.r2one  3.r2two   4.siren  5.chewy    6.radar   7.mariobro
    :  8.laugh   9.what   10.nova   11.hello 12.mode1   13.mode2  14.mode3
    :  15.mode4  16.fon   17.foff   18.sustain 19.warn  20.danger 21.critical
    :  22.halt
    :sounds_req below is that count - if the card holds fewer, boot says so.
   -------------------------------------------------------
*/
static const uint8_t PIN_MP3_TX = 1;
static const uint8_t PIN_MP3_RX = 0;
SoftwareSerial softwareSerial(PIN_MP3_RX, PIN_MP3_TX);
DFRobotDFPlayerMini DFPlayer;

unsigned int mp3Interval = 50;
unsigned long lastMP3Update = 0;
int mp3_queue[5] = {0,0,0,0,0};   //tracks waiting to play, so nothing blocks
int mp3_status = 0;               //1 while the queue is being worked through
int sound_vol = 12;               //current volume (1-30)
int sounds_req = 22;              //how many tracks the sketch expects
int sounds_sd = 0;                //how many the card actually holds
int sound_cnt = 0;                //countdown before follow mode speaks again
int sound_cur = 0;                //reload value for sound_cnt

//volume potentiometer polling. Left in place but currently unread - the pot
//on the switch panel is not wired up. See the DEV note in mp3_volume().
unsigned int potInterval = 10000;
unsigned long lastPotUpdate = 0;


/*
   -------------------------------------------------------
   PIR motion sensors and follow mode
   -------------------------------------------------------
*/
unsigned int pirInterval = 150;
unsigned long lastPIRUpdate = 0;
unsigned int pirDelay = 3;        //cycles of the state machine, NOT milliseconds
int pir_frontState = LOW;
int pir_leftState = LOW;
int pir_rightState = LOW;
int pir_halt = 1;                 //1 = motion triggers the intruder alert
byte pir_reset = 0;               //1 while recovering from an alert
int pir_wait = 0;                 //cycles to ignore the sensors for, after a trigger
byte pir_state = LOW;             //whether an alert is currently running
byte pir_val = 0;
int pir_repeat_cnt = 0;           //consecutive quiet polls, used to stop following
int pir_is_active = pir_active;   //the user's setting, so routines can restore it
int follow_dir = 0;               //which way follow mode last decided to go
int follow_dir_prev = 0;


/*
   -------------------------------------------------------
   Ultrasonic distance sensors (left and right, read via the slave)
   -------------------------------------------------------
*/
unsigned int ussInterval = 250;
unsigned long lastUSSUpdate = 0;
int distance_alarm = 10;              //cm at which an obstacle counts as too close
int distance_alarm_set = 0;           //consecutive triggers, to reject one-off bad reads
int distance_tolerance = 5;           //cm a reading must change by before it is believed
int distance_l;                       //latest left distance
int prev_distance_l;                  //previous left distance, to reject false positives
int distance_r;                       //latest right distance
int prev_distance_r;                  //previous right distance
int uss_is_active = uss_active;       //the user's setting, so routines can restore it


/*
   -------------------------------------------------------
   MPU6050 IMU
    :the register-level driver is in MPU6050_conf.h; these are the fused
    :results and the state get_mpu() keeps between reads
   -------------------------------------------------------
*/
const int MPU = 0x68;
unsigned int mpuInterval = 10;
unsigned int mpuInterval_prev = 400;  //slower interval used for the very first read
unsigned long lastMPUUpdate = 0;
float mroll, mpitch, myaw;            //current fused attitude, in degrees
float mroll_prev, mpitch_prev;        //previous values, for the trigger threshold
float accAngleX, accAngleY, gyroAngleX, gyroAngleY;
float mpu_mroll = 0.00;               //attitude captured at startup, treated as level
float mpu_mpitch = 0.00;
float mpu_myaw = 0.00;
float mpu_trigger_thresh = 0.05;      //degrees of change before the legs respond
float elapsedTime, currentTime, previousTime;
int mpu_is_active = mpu_active;       //the user's setting, so routines can restore it


/*
   -------------------------------------------------------
   PS2 remote
   -------------------------------------------------------
*/
PS2X ps2x;
unsigned int ps2Interval = 50;
unsigned long lastPS2Update = 0;
int ps2_select = 1;               //active button set, 1-4, cycled by SELECT

//ps2 debug reporting, toggled at runtime by the 'ps2' serial command.
//NOTE: set this to 1 here (before flashing) to poll the controller with servo
//      output left DISABLED - lets the remote be checked on the bench without
//      the robot standing up. Toggling it via serial does not touch pwm_oe.
byte ps2_debug = 0;
unsigned int ps2DebugInterval = 120;    //throttles analog stick reporting
unsigned long lastPS2Debug = 0;
unsigned long lastPS2Beat = 0;
const byte ps2_deadzone = 8;            //sticks rarely rest at exactly 128
const unsigned int ps2_btn_mask[16] = {
  PSB_START, PSB_SELECT, PSB_PAD_UP, PSB_PAD_DOWN, PSB_PAD_LEFT, PSB_PAD_RIGHT,
  PSB_TRIANGLE, PSB_CROSS, PSB_CIRCLE, PSB_SQUARE,
  PSB_L1, PSB_R1, PSB_L2, PSB_R2, PSB_L3, PSB_R3
};
const char* const ps2_btn_name[16] = {
  "START", "SELECT", "UP", "DOWN", "LEFT", "RIGHT",
  "TRIANGLE", "CROSS", "CIRCLE", "SQUARE",
  "L1", "R1", "L2", "R2", "L3", "R3"
};


/*
   -------------------------------------------------------
   Slave board and serial commands
   -------------------------------------------------------
*/
byte serial_oled = 0;             //mirrors the slave's mode flag: 0 = system, 1 = OLED.
                                  //Managed by rgb_request() / oled_request(), not by hand.
int serial_resp;                  //last value the slave sent back
unsigned int serialInterval = 60;
unsigned long lastSerialUpdate = 0;
String serial_input;              //characters collected so far for the current command


/*
   -------------------------------------------------------
   Current draw monitoring (ACS712)
    :a servo that has reached its target but is still pulling hard is jammed,
    :which is what amperage_check() is looking for
   -------------------------------------------------------
*/
unsigned int ampInterval = 15000; //shortened automatically as readings get worse
unsigned long lastAmpUpdate = 0;
int amp_cnt = 0;                  //consecutive over-limit readings so far
int amp_thresh = 10;              //how many in a row before shutting the servos down
int amp_warning = 0;              //current warning level, 0-2
int amp_loop = 1;                 //0 stops rescheduling the check
float amp_limit = 6.5;            //amps drawn before the alarm starts counting


/*
   -------------------------------------------------------
   Battery monitoring
    :batt_levels is a descending ladder - each rung crossed raises the warning
    :level shown on the OLED, and the last one halts the system
   -------------------------------------------------------
*/
unsigned long batteryInterval = 3000;
unsigned long lastBatteryUpdate = 0;
int batt_cnt = 0;                 //readings averaged so far
float batt_voltage = 11.8;        //approx fully charged battery minimum nominal voltage
float batt_voltage_prev = 11.8;   //comparison voltage to prevent false positives
float avg_volts = 0;              //running total being averaged
float batt_levels[10] = {         //voltage drop alarm levels(10)
   11.2, 11.1, 11.0, 10.9, 10.8,
   10.7, 10.6, 10.5, 10.4, 10.3,
};


/*
   -------------------------------------------------------
   Movement parameters
    :the numbers a movement routine reads when loop() next advances it
   -------------------------------------------------------
*/
unsigned long lastMoveDelayUpdate = millis();
unsigned int moveDelayInterval = 0;   //0 = no scripted routine is running
int move_delays[16] = {0,0,0,0,0,0,0,0,0,0,0,0,0,0,0,0};          //ms to wait at each step
int move_delay_sequences[16] = {0,0,0,0,0,0,0,0,0,0,0,0,0,0,0,0}; //which routine each step runs
int move_delay = 0;               //delay applied between sequenced servo moves
int move_loops = 0;               //repeats left in the current movement, 0 = run forever
int move_switch = 0;              //sub-state used by the multi-phase routines

float move_steps_min = -100;      //bounds the sticks and serial commands map into
float move_steps_max = 100;
float move_steps = 0;             //the main "how far" input to most routines
float move_steps_x = 0;           //kinematics: sideways body offset
float move_steps_y = 0;           //kinematics: forward/back body offset
float move_steps_yaw_x = 0;       //kinematics: yaw driven by the right stick X
float move_steps_yaw_y = 0;       //kinematics: yaw driven by the right stick Y
float move_steps_yaw = 0;         //kinematics: yaw while L3 is held
float move_steps_kx = 0;          //kinematics: x translation
float move_steps_ky = 0;          //kinematics: y translation

//travel limits each input is mapped into, {min, max}
int move_c_steps[2] = {-50, 50};      //coxa
int move_x_steps[2] = {-30, 30};      //sideways
int move_y_steps[2] = {-180, 130};    //forward / backward
int move_z_steps[2] = {-50, 50};      //ride height
float x_dir_steps[2] = {-22, 22};     //stick range for x_dir
float y_dir_steps[2] = {-22, 22};     //stick range for y_dir
float z_dir_steps[2] = {-40, 40};     //stick range for z_dir
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
void loop() {
  update_servos();
/*
   -------------------------------------------------------
   Check for Moves
    :check if any scripted, sequenced, or dynamic moves are active
    :and execute accordingly along with any required variables defined
   -------------------------------------------------------
*/
  if (move_sequence) {
    run_sequence();
  } else if (move_x_axis) {
    x_axis();
  } else if (move_y_axis) {
    y_axis();
  } else if (move_pitch_body) {
    pitch_body();
  } else if (move_pitch) {
    pitch(x_dir);
  } else if (move_roll_body) {
    roll_body();
  } else if (move_roll) {
    roll();
  } else if (move_trot) {
    step_trot(x_dir);
  } else if (move_forward) {
    step_forward(x_dir);
  } else if (move_backward) {
    step_backward(x_dir);
  } else if (move_left) {
    ramp_dist = 0.25;
    ramp_spd = 1.5;
    use_ramp = 0;
    step_left_right(1, x_dir, y_dir);
  } else if (move_right) {
    ramp_dist = 0.25;
    ramp_spd = 1.5;
    use_ramp = 0;
    step_left_right(0, x_dir, y_dir);
  } else if (move_march) {
    step_march(x_dir, y_dir, z_dir);
  } else if (move_wake) {
    wake();
  } else if (move_wman) {
    ramp_dist = 0.2;
    ramp_spd = 0.5;
    use_ramp = 1;
    wman();
  } else if (move_funplay) {
    funplay();
  } else if (move_look_left) {
    look_left();
  } else if (move_look_right) {
    look_right();
  } else if (move_roll_x) {
    roll_x();
  } else if (move_pitch_y) {
    pitch_y();
  } else if (move_kin_x) {
    move_kx();
  } else if (move_kin_y) {
    move_ky();
  } else if (move_yaw_x) {
    yaw_x();
  } else if (move_yaw_y) {
    yaw_y();
  } else if (move_yaw) {
    yaw();
  } else if (move_servo) {
    move_debug_servo();
  } else if (move_leg) {
    move_debug_leg();
  }

/*
   -------------------------------------------------------
   Check State Machines
    :check active state machine(s) for execution time by its respective interval
   -------------------------------------------------------
*/
  if (ps2_active) {
    if (millis() - lastPS2Update > ps2Interval) ps2_check();
  }

  if (serial_active) {
    if (millis() - lastSerialUpdate > serialInterval) serial_check();
  }

  if (pir_active) {
    if (millis() - lastPIRUpdate > pirInterval) pir_check();
  }

  if (mpu_active) {
    if(millis() - lastMPUUpdate > mpuInterval) get_mpu();
  }

  if (uss_active) {
    if (millis() - lastUSSUpdate > ussInterval) uss_check();
  }

  if (amp_active) {
    if (ampInterval && millis() - lastAmpUpdate > ampInterval) amperage_check(amp_loop);
  }

  if (batt_active) {
    if(millis() - lastBatteryUpdate > batteryInterval) battery_check();
  }

  if (moveDelayInterval && millis() - lastMoveDelayUpdate > moveDelayInterval) {
    delay_sequences();
  }

  if (mp3_active && mp3_status) {
    if(millis() - lastMP3Update > mp3Interval) check_mp3();
  }
//  if (potInterval && millis() - lastPotUpdate > potInterval) mp3_volume(-1);
}



/*
   -------------------------------------------------------
   Hardware Functions
   -------------------------------------------------------
*/
/*
   -------------------------------------------------------
   Update Servos
    :check if servo(s) need updating
    :this is the core functionality of Nova
   -------------------------------------------------------
*/
void update_servos() {
  //update coxas
  s_RFC.Update();
  s_LFC.Update();
  s_RRC.Update();
  s_LRC.Update();

  //update femurs
  s_RFF.Update();
  s_LFF.Update();
  s_RRF.Update();
  s_LRF.Update();

  //update tibias
  s_RFT.Update();
  s_LFT.Update();
  s_RRT.Update();
  s_LRT.Update();
}











































void powering_down(void) {
  digitalWriteFast(LED_PIN, !digitalReadFast(LED_PIN));
  if (debug) Serial.println ("System Shutting Down... ");

  if (oled_active) {
    oled_request(OLED_HALTED);
  }
  if (mp3_active) {
    mp3_play(22);
    delay(2500);
    mp3_play(5);
  } else if (buzz_active) {
    for (int b = 12; b > 0; b--) {
      tone(BUZZ, random(1, 12) * 100);
      delay(50);
      noTone(BUZZ);
      delay(25);
    }
    noTone(BUZZ);
  }

  set_stop_active();
  init_home();

  if (rgb_active) {
    rgb_request(RGB_SPEED_1000 RGB_FADE_BLUE);
  }
  if (oled_active) {
    oled_request(OLED_HALTED);
  }
  delay(2500);
}

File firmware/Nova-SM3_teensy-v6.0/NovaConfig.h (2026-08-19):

/*
 *   NovaSM3 - a Spot-Mini Micro clone
 *   Version: 6.0
 *   Version Date: 2026-08-19
 *
 *   Original Author:  Chris Locke - cguweb@gmail.com
 *   Nova's website:  https://novaspotmicro.com
 *   GitHub Project:  https://github.com/cguweb-com/Arduino-Projects/tree/main/Nova-SM3
 *
 *   -----------------------------------------------------------------------
 *   BUILD CONFIGURATION - this is the file you edit
 *   -----------------------------------------------------------------------
 *
 *   Everything here describes THIS robot and THIS build: which subsystems are
 *   fitted, how much the sketch prints while it runs, and what is wired where.
 *   Nothing here is state - runtime variables live in the main sketch next to
 *   the code that uses them.
 *
 *   Per-servo calibration is NOT here. Home positions and travel limits are
 *   physical measurements of one assembled robot and live in NovaServos.h.
 *   -----------------------------------------------------------------------
*/

#ifndef NOVA_CONFIG_H
#define NOVA_CONFIG_H

#define VERSION 6.0


/*
   -------------------------------------------------------
   Debug output
    :each flag enables one category of Serial.print tracing

    *** READ THIS BEFORE RUNNING NOVA OFF THE TETHER ***
    On a Teensy, printing to a serial port that nothing is listening on will
    stall the board. If ANY flag below is set, Nova will appear dead until you
    plug in USB. Set them all to 0 before running untethered.

    `plotter` is different: it suppresses the ordinary human-readable prints
    so the remaining numeric output can be fed to the Arduino Serial Plotter,
    which only understands "label:value" lines. That is why so much printing
    in this sketch is wrapped in `if (!plotter)`.
   -------------------------------------------------------
*/
const byte debug   = 1;           //general progress and boot messages
const byte debug1  = 0;           //ps2 button presses and PIR sensor events
const byte debug2  = 0;           //individual servo steps
const byte debug3  = 0;           //ramping and move sequencing
const byte debug4  = 1;           //amperage draw and battery voltage
const byte debug5  = 0;           //MPU6050 roll / pitch / yaw
const byte debug6  = 0;           //i2c traffic to and from the Nano slave
const byte debug7  = 0;           //ultrasonic sensor distances
const byte plotter = 0;           //format output for the Serial Plotter (turn debug1 off)


/*
   -------------------------------------------------------
   Fitted hardware
    :set to 0 for anything this robot does not have, or that you want to keep
    :quiet while testing something else. Each flag is checked both in setup()
    :(to skip initialising the device) and in loop() (to skip polling it).
    :
    :Several are also mirrored into a `*_is_active` variable at startup, so
    :routines can switch a subsystem off temporarily and put it back exactly
    :as the user configured it here - see the main sketch.
   -------------------------------------------------------
*/
byte slave_active   = 1;          //Arduino Nano slave: OLED, RGB eyes, ultrasonics
byte pwm_active     = 1;          //PCA9685 servo driver - without this Nova cannot move
byte ps2_active     = 1;          //PS2 wireless remote
byte serial_active  = 1;          //typed commands over USB serial
byte mpu_active     = 0;          //MPU6050 IMU for self-levelling
byte rgb_active     = 1;          //NeoPixel eyes (driven via the slave)
byte oled_active    = 1;          //SSD1331 display (driven via the slave)
byte pir_active     = 0;          //three PIR motion sensors
byte uss_active     = 0;          //two ultrasonic distance sensors (via the slave)
byte amp_active     = 0;          //ACS712 current sensor / stall detection
byte batt_active    = 0;          //battery voltage monitoring and low-battery halt
byte buzz_active    = 0;          //piezo buzzer sound effects
byte melody_active  = 1;          //musical startup tunes
byte mp3_active     = 1;          //DFPlayer Mini MP3 module
byte splash_active  = 1;          //play the full boot animation on the OLED
byte quick_boot     = 1;          //skip most boot graphics and sounds - much faster to test with
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

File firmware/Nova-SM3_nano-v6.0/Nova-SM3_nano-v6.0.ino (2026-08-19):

/*
 *   NovaSM3 - a Spot-Mini Micro clone
 *   Version: 6.0
 *   Version Date: 2026-08-19
 *
 *   TARGET BOARD: Arduino Nano  --  this is the SLAVE controller.
 *   Its partner is Nova-SM3_teensy-v6.0, the master that does all the
 *   thinking: servos, IMU, remote, sensors and serial commands.
 *
 *   Original Author:  Chris Locke - cguweb@gmail.com
 *   Nova's website:  https://novaspotmicro.com
 *   GitHub Project:  https://github.com/cguweb-com/Arduino-Projects/tree/main/Nova-SM3
 *   YouTube Playlist:  https://www.youtube.com/watch?v=00PkTcGWPvo&list=PLcOZNHwM_I2a3YZKf8FtUjJneKGXCfduk
 *
 *   Version 6.0 is a readability pass over version 5.1 by Jeremy, with
 *   Claude Code. Behaviour is unchanged. See README.md for the full list.
 *
 *
 *   WHAT THIS BOARD DOES
 *   --------------------
 *   The Nano owns only the peripherals wired directly to it:
 *
 *     - the SSD1331 SPI colour OLED
 *     - four NeoPixel "eyes"
 *     - two ultrasonic distance sensors
 *     - a few bytes of EEPROM holding its own settings
 *
 *   It makes no decisions. The Teensy sends single-byte commands over i2c and
 *   this board carries them out. Every command byte is named and documented in
 *   NovaSlaveProtocol.h, which is shared with the master.
 *
 *
 *   HOW IT RUNS
 *   -----------
 *   Two i2c interrupt handlers and one non-blocking loop:
 *
 *     receiveEvent()    stores the incoming byte in `req`
 *     requestCallback() acts on `req` and returns a two-byte response
 *     loop()            advances the LED animation and the display on their
 *                       own millis() timers, and watches the OLED button
 *
 *   The one piece of state that changes what a byte means is `serial_oled`:
 *   0 = the byte is a system command, 1 = it is a display command. The byte
 *   'X' toggles it. See NovaSlaveProtocol.h for the full explanation.
 *
 *
 *   HOW THIS SKETCH IS ORGANISED
 *   ----------------------------
 *     Nova-SM3_nano-v6.0.ino   globals, setup(), loop(), i2c handlers  <- start here
 *     NovaSlaveProtocol.h      the command bytes - keep in sync with the master's copy
 *     NovaBitmap.h             the boot logo
 *     Display.ino              everything drawn on the OLED
 *     Leds.ino                 the NeoPixel eye animations
 *     Settings.ino             EEPROM settings and the self-reset
 *
 *
 *   MEMORY
 *   ------
 *   The Nano is nearly full. Before adding anything, check the compiler's
 *   final report - there is very little flash headroom left.
 *
 *   RELEASE NOTES (v5.1, carried over)
 *      Added saving / retrieving eeprom data to enable changing settings from the master
 *      Replaced i2c oled with SPI oled
 *      Added NewPing for ultrasonic sensors
 *      Added command switches for active settings
 *      Added battery gauge display code
 *      Added radar target display code
*/

//set Nova SM3 version
#define VERSION 6.0

#include <Wire.h>
#include <Adafruit_NeoPixel.h>
#include <Adafruit_GFX.h>
#include <Adafruit_SSD1331.h>
#include <SPI.h>
#include <EEPROM.h>
#include <NewPing.h>

//the command bytes this board understands, shared with the master.
//IMPORTANT: this file must stay identical to the master's copy.
#include "NovaSlaveProtocol.h"
#include "NovaBitmap.h"


/*
   -------------------------------------------------------
   Settings
    :these are DEFAULTS ONLY. load_ep_data() overwrites all five from EEPROM
    :during setup, so changing a value here has no effect on a board that has
    :already been run - it will read back whatever EEPROM holds.
    :
    :The master changes splash_active remotely with the reboot commands, which
    :is what makes the setting persist across a power cycle.
   -------------------------------------------------------
*/
byte debug1 = 0;                  //print i2c traffic and display activity to serial
byte rgb_active = 1;              //NeoPixel eyes fitted
byte oled_active = 1;             //OLED display fitted
byte uss_active = 1;              //ultrasonic sensors fitted
byte splash_active = 1;           //play the boot animation


/*
   -------------------------------------------------------
   Pin map - Arduino Nano (slave)
   -------------------------------------------------------

     pin  | used for
     -----+---------------------------------------------------
      2   | NeoPixel eyes data
      3   | self-reset, wired back to this board's own RESET
      4   | right ultrasonic ECHO
      5   | right ultrasonic TRIGGER
      6   | left ultrasonic ECHO
      7   | left ultrasonic TRIGGER
      8   | OLED reset
      9   | OLED data/command select
      10  | OLED chip select
      11  | OLED data      (hardware SPI MOSI)
      12  | OLED on/off button
      13  | OLED clock     (hardware SPI SCK)
      A3  | eye brightness potentiometer
      A4  | i2c SDA to the master
      A5  | i2c SCL to the master
*/

//i2c link to the master
#define SLAVE_ID 1                //this board's i2c address
#define RESET_PIN 3               //pulled LOW to reboot this board on command
byte serial_oled = 0;             //0 = incoming bytes are system commands, 1 = display commands
int resp;                         //value returned to the master on the next request
char req;                         //most recent command byte received


/*
   -------------------------------------------------------
   OLED display (SSD1331, hardware SPI)
    :SPI clock and data are fixed by the hardware to pins 13 and 11, so only
    :the three control lines are configurable here
   -------------------------------------------------------
*/
#define OLED_CS 10
#define OLED_DC 9
#define OLED_RST 8
#define SCREEN_WIDTH 96
#define SCREEN_HEIGHT 64
Adafruit_SSD1331 display = Adafruit_SSD1331(OLED_CS, OLED_DC, OLED_RST);

//16-bit RGB565 colours
#define WHITE 0xFFFF
#define GRAY 0xAAAA
#define BLACK 0x0000
#define BLUE 0x001F
#define RED 0xF800
#define GREEN 0x07E0
#define CYAN 0x07FF
#define MAGENTA 0xF81F
#define YELLOW 0xFFE0

unsigned long lastOLEDUpdate = 0;
unsigned int oledInterval = 250;
unsigned long lastOLEDClear = 0;
unsigned long oledClearInterval = 5000;   //blank the screen this long after the last command
int oled_command = 0;                     //screen waiting to be drawn, 0 = nothing pending
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

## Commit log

2026-08-19 Initial commit: Nova SM3 quadruped firmware (modded, code only)
    Nova SM3 is a Spot-Mini Micro clone quadruped robot. This repository
    carries the Arduino sketches only. The printable STLs, wiring diagrams,
    MP3 assets and parts list are large and unchanged from upstream, so they
    are not tracked here - see .gitignore and the README.
    Derived from Chris Locke's Nova SM3 (https://novaspotmicro.com,
    github.com/cguweb-com/Arduino-Projects), MIT licensed; his copyright
    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
2026-09-03 docs: add mechanical redesign evidence and CAD comparison assets
    The central claim of this fork is that the leg geometry was redesigned
    around servos the original was not drawn for. This makes that claim
    inspectable rather than asserted.
    - hardware/cad/original/: Chris Locke's reference STLs, unmodified, so
    the comparisons are reproducible and the attribution is concrete.
    - hardware/cad/modified/: my geometry, as STL and as native SolidWorks
    parts. The feature trees start with Imported1 - the original STL as a
    base body - with my sketches and features on top, which is the actual
    provenance of the modification.
    - hardware/cad/comparisons/: before/after figures rendered from the STLs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
    [SM3_Frame_LeftCoax.stl, SM3_Frame_LeftFemur.stl, SM3_Frame_LeftTibia.stl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]
2026-09-03 docs: document electronics integration, bring-up and open gaps
    Covers the per-subsystem bring-up strategy behind Code/Tests/: eight
    standalone sketches that include none of the main firmware, so a pass
    isolates wiring and hardware faults from firmware faults.
    Records the hazards that are in the source as warnings because they were
    live problems - the Teensy 4.0 not being 5V tolerant on the PS2 data
    line, the active-low OE pin and its boot ordering, current and battery
    sense sharing pin A1, and debug flags stalling an untethered boot.
    The modified wiring diagram is not yet available; hardware/electronics/
    holds a placeholder describing what belongs there and stating that it
    should be commit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
2026-09-03 docs: rewrite README around the engineering contribution
    The previous README described the firmware fork. This describes what was
    actually engineered here and separates it from what was inherited.
    Leads with the constraint (components not sourceable locally), the design
    rule it forced (preserve the servo horn interface, rebuild the structure
    around it), and the consequences that follow through mechanical,
    electrical and firmware work. Adds an explicit split of Chris Locke's
    work from mine.
    Corrects two things the earlier notes had backwards:
    - The controller change is not NRF to PS2. Upstream's newer versions use
    an nRF module with a custom remote; the older ones use PS2. This fork
    bui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
2026-09-03 docs: add close-up evidence of PCB assembly and wiring bring-up
    The wide integration shot does not resolve the board detail that backs
    the electronics claims. This crop does: the project's own controller PCB
    hand-populated with JST servo headers, an Arduino Nano, an MPU6050
    breakout, a DIP switch and screw terminals, next to the step-down
    converter with its toroidal inductor, capacitor bank and heatsinks.
    It also shows the masking-tape labels marking +VCC / SDA / SCL / OE /
    GND, which are the concrete artifact of tracing the I2C and
    output-enable lines during bring-up.
    Lets the PCB assembly claim rest on a visible board rather than on
    assertion.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
2026-09-03 docs: add revised wiring diagram and document the power rework
    The modified wiring diagram is now available, so the electronics work
    rests on the drawing rather than on recollection.
    Committed at full resolution (6000 x 4712) as the drawing itself rather
    than redrawn or summarised, plus a cropped revision block for legibility.
    It is a revision of Chris Locke's v5.2b pictogram: base artwork his,
    revisions mine, and the README says so.
    This supplies the evidence the previous commit said was missing:
    - Cascaded converters. The XL6009 5.4V converter took its input from the
    6.8V converter's output block, so the two ran in series and everything
    downstream inherited the first stage's droop a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
    [SM3_Frame_Coxa_MOD.SLDPRT, SM3_Frame_Coxa_MOD.stl, SM3_Frame_FemurTibia_MOD.SLDPRT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]
2026-09-03 docs: document the femur two-into-one merge; rename CAD files
    The femur change was previously described only as servo accommodation
    and compared against the wrong baseline. It is a tolerance decision.
    The original femur is two separately printed parts that bolt together, a
    structural frame and a cover. They are merged here into one printed part,
    so the servo pocket and the knee mating features sit in one solid off one
    origin instead of either side of a bolted joint whose alignment depends
    on print tolerance, warp and fastener preload.
    Corrects the earlier comparison, which measured the merged part against
    the frame alone and reported it as 59% heavier. Measured against both
    original parts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
    [SM3_Cover_LeftFemur.stl]
2026-09-03 docs: correct the controller history and drop em dashes
    Corrects an overcorrection in the README. An earlier revision said the
    NRF-to-PS2 change was "the other way round", reading the firmware header
    alone. The wiring diagram settles it: revision 3 records the NRF24L01
    being removed and a Yahboom 2.4G PS2 receiver fitted in its place. Both
    things are true and they are not in conflict. Upstream's newer versions
    and the v5.2b board are built around an nRF module and a custom remote,
    and this build removed that module, wired a PS2 receiver, and used the
    older PS2 firmware path rather than fabricating a remote.
    Also replaces em and en dashes throughout the documentation with commas,
    colons, par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
2026-09-03 docs: show the femur merge visually; use coax/femur/tibia consistently
    The femur figure asserted the two-into-one merge in its caption but did
    not show it. Three panels of separate parts at different orientations do
    not demonstrate that two became one.
    Replaced with a figure that does: the two original parts shown apart,
    then overlaid in their assembled position, then the merged single part.
    The assembled view is not posed. SM3_Frame_LeftFemur and
    SM3_Cover_LeftFemur are both exported about a shared origin, so importing
    them untranslated puts them in their real fit, with the cover visibly
    wrapping the frame. Colour-coded with a legend so the two parts stay
    distinguishable, and an arrow carr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
    [SM3_Frame_Coax_MOD.SLDPRT, SM3_Frame_Coax_MOD.stl, SM3_Frame_FemurTibia_MOD_PrintPlate.SLDPRT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]
2026-09-03 docs: rebuild the portfolio around real media and correct the mechanical record
    Restructures the repository into mechanical / electronics / firmware and
    rewrites the mechanical and electronics documentation from the source
    evidence. The firmware write-up from 4444681 is kept and moved to
    firmware/README.md with its sketches, so its relative links still resolve.
    Corrects three claims the previous documentation got wrong:
    - The femur was never merged from two parts into one. Both the original and
    my version print as two parts. The old "56.98 + 33.26 = 90.24 against
    90.73, a 0.5% difference" argument rested on a wrong figure for the
    original frame (66.02, not 56.98) and on a coincidence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
    [SM3_Cover_LeftFemur.stl, SM3_Frame_LeftCoax.stl, SM3_Frame_LeftFemur.stl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]
2026-09-03 docs(firmware): document the buses, the bit-banged PS2 link and why the nRF was skipped
    The robot has no single bus: I2C on two controllers (with the IMU and the
    Nano sharing Wire1), PWM out of the PCA9685, a bit-banged PS2 link, UART to
    the DFPlayer, plus SPI, a timed single wire and pulse timing on the slave.
    Verified against the includes and PS2X_lib.cpp rather than assumed.
    Records that the nRF24L01 was left unpopulated by choice: the reference
    design pairs it with a custom-built handheld remote, and using an
    off-the-shelf PS2 gamepad avoided building one.
    Claude-Session: https://claude.ai/code/session_0118xSrsY9DGCPpSMM1MQ3nt
2026-09-03 docs(mechanical): show the RDS3218 in its bracket and the femur seam
    Two crops from the full-resolution leg photograph: the servo held in its
    aluminium U bracket, which is the mounting arrangement the whole redesign
    had to accommodate, and the joint between the two femur parts on the
    assembled robot.
    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
2026-09-03 docs(mechanical): document the SM2 backpack tail
    The PS2 receiver replaced a radio that was soldered to the board, so it had
    nowhere to live. The backpack from the Nova SM2 was mounted on a new back
    panel so the receiver protrudes from the body like a tail, keeping the
    antenna out of the electronics bay.
    Adds the upstream SM2 backpack body and cover, my back panel
    (finalnewbackpanel_fixed.stl, 61.02 x 99.57 x 7.04 mm, 8.62 cm3), a
    comparison figure and a frame from the build video showing the tail fitted.
    Records that the mounting holes were melted with a soldering iron and the
    assembly secured with inserts and nuts, rather than presenting it as a
    CAD-clean fit.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
    [SM2_BackPackBody.stl, SM2_BackPackCover.stl, modified_backpanel.stl]
2026-09-03 docs: show the DS3218 against the RDS3218, and restore the sourcing constraint
    Adds the side-by-side that the mechanical argument was missing: the DS3218
    carries its mounting tabs on the case, the RDS3218 has none and hangs in a
    separate U bracket, so the printed part has to capture the bracket instead
    of the servo. The DS3218 image is a manufacturer product photograph and is
    credited as such in the root README rather than presented as my own.
    Also records that the build happened in the Philippines, where much of the
    original bill of materials was not practically sourceable, which is what
    put a different servo in the design in the first place. Confirms the
    backpack fasteners were brass heat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
2026-09-03 docs: correct which drawing was wrong, and add the diagnostics behind each fix
    Electronics:
    - The schematic is accurate and was the reference used for testing. The
    pictogram is the document that was wrong. The previous text blamed both.
    - Drops the 'Shorted!' framing. That annotation is not a separate finding:
    it is the PIR ground drop landing on the +5V rail, which is revision 2,
    so it is folded in there and described as the short it is.
    - Records the diagnosis behind the converter rework: startup was
    inconsistent, the buck output measured differently power-on to power-on
    but read steady when hot-wired straight to the pack, which pointed at
    source impedance upstream rather than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
2026-09-03 Fix description of Nova SM3 controller board
    Corrected a description of the Nova SM3 controller board to clarify that it is Chris' project PCB and included details about component rerouting.
